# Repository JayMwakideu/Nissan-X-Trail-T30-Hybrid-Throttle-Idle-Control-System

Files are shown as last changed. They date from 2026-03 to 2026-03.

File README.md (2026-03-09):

# 🏎️ Nissan X-Trail T30 "Hybrid" Throttle & Idle Control System

### **Project Aim: Permanently Solving Electronic Throttle Body (ETB) Failure**

The Nissan X-Trail T30 (QR20DE/QR25DE) suffers from a notorious flaw: Electronic Throttle Body motor failure. This leads to erratic idling, Limp Mode, and expensive repairs.

This project bypasses the electronic failure points entirely by converting the system to a **Manual Cable-Driven Throttle**. An **Arduino-controlled Servo** is then used as a "helper" to manage critical idle air compensation (AC load, Power Steering load, and Cold Starts), creating a reliable, bulletproof solution.

---

## 🛠️ 1. Mechanical Modification: The "Hybrid" Body

To bypass the unreliable electronics, the throttle body must be physically modified to accept a manual accelerator cable and an idle-assist servo shaft.

### **Transformation Steps:**
1.  **Shaft Extension:** Weld a steel extension or a threaded bolt to the end of the main butterfly valve shaft.
2.  **The Pulley:** Attach a circular pulley to the new shaft extension for the manual accelerator cable.
3.  **The Helper Servo:** Mount a high-torque servo using a 3D-printed bracket. The servo arm "pushes" the throttle linkage to "crack" the butterfly open slightly (0–15%) to maintain idle.
4.  **Failsafe Return Spring:** **CRITICAL SAFETY STEP.** Install a heavy-duty external spring to ensure the throttle snaps shut if the cable or servo fails.

### **Modification Reference Photos**
*(Upload your photos to the repository to activate these links)*

| Modified Throttle Body | Engine Bay Installation | Gas Pedal Linkage |
| :---: | :---: | :---: |
| Throttle | Engine | Pedal |

---

## 🔌 2. Wiring & Electronics

The Arduino (Uno/Nano) acts as the new "Idle Control Unit," monitoring engine loads and adjusting the servo position in real-time.

### **Complete Wiring Table**

| Function | Pin | Component | Note |
| :--- | :--- | :--- | :--- |
| **RPM Input** | D2 | PC817 Optocoupler | Tapped from Ignition Coil (Must use Opto!) |
| **PSP Switch** | D3 | OEM Pressure Switch | Detects Power Steering load |
| **AC Signal** | D4 | AC Clutch Wire | Detects AC Compressor load |
| **Temp Sensor** | D6 | DS18B20 | Reads engine coolant temperature |
| **Servo Output** | D9 | MG996R / SG90 | Controls physical idle opening |
| **Display** | A4/A5 | SSD1306 OLED | I2C Data/Clock |
| **Buzzer** | D11 | Active 5V Buzzer | Stall Alarm (RPM < 550) |
| **Voltage** | A0 | Resistor Divider | Optional Battery Monitor (30k/7.5k) |

---

## 🖥️ 3. Software Logic & UI

The code uses a simplified PID loop to maintain target RPM based on input loads.

### **Dashboard Interface Gallery**
Here is a sequence showing the bootloader, main telemetry dash, and the EEPROM settings menu.

<table border="0">
  <tr>
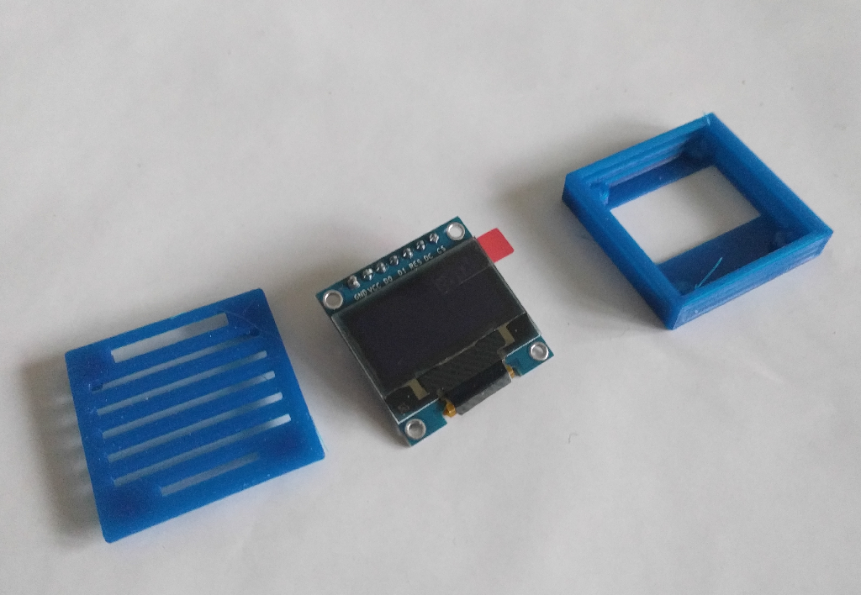
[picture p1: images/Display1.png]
    <td align="center"><br><em>Boot Logo</em></td>
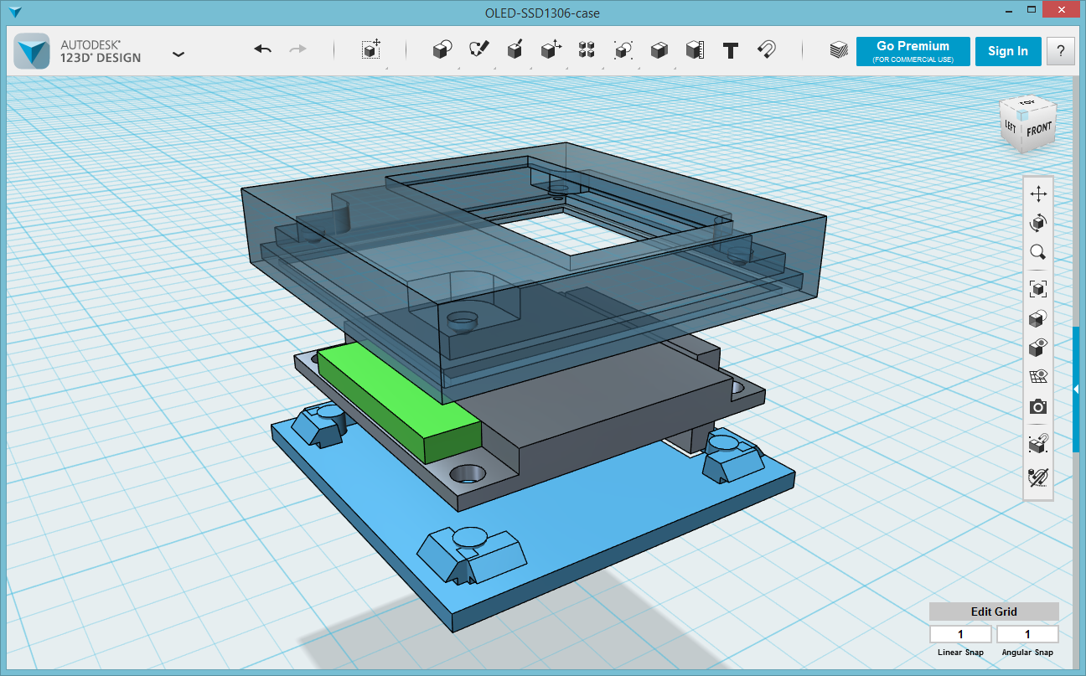
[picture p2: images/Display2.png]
    <td align="center"><br><em>Main Telemetry</em></td>
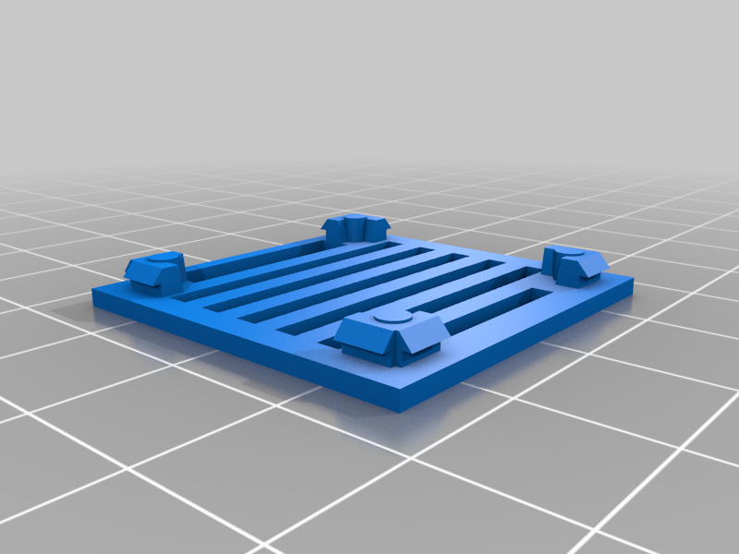
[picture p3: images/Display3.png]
    <td align="center"><br><em>Menu System</em></td>
  </tr>
  <tr>
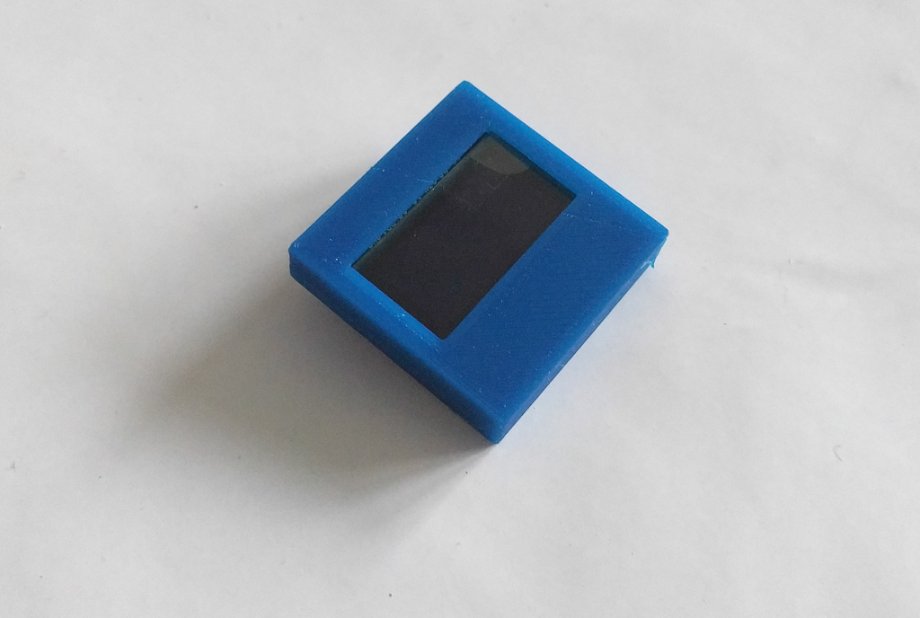
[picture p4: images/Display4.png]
    <td align="center"><br><em>Settings Adjust</em></td>
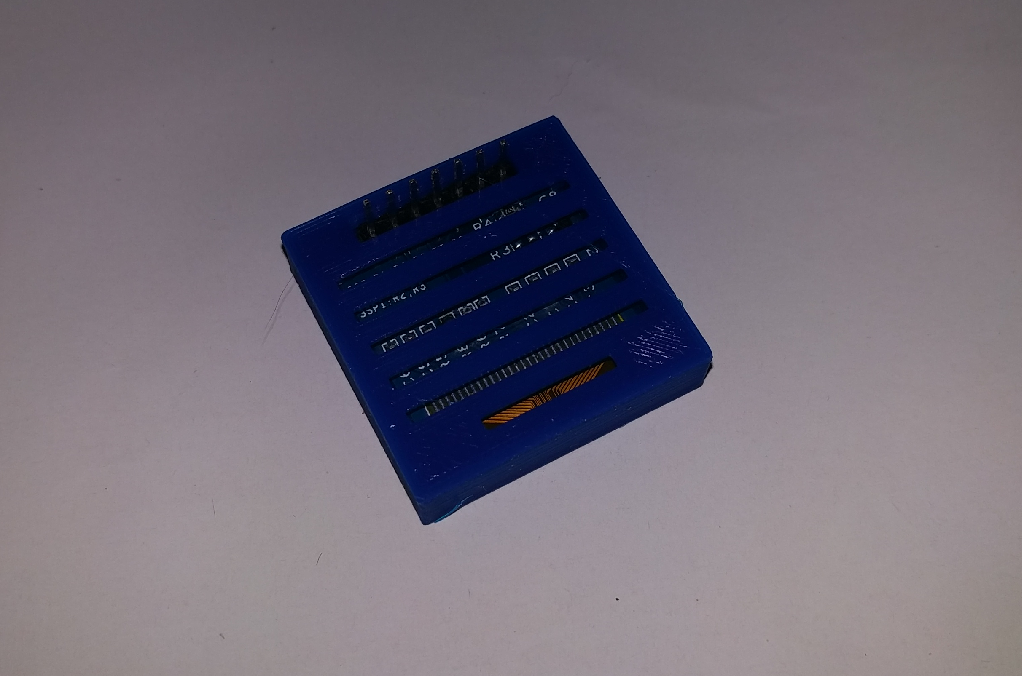
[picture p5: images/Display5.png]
    <td align="center"><br><em>Save Prompt</em></td>
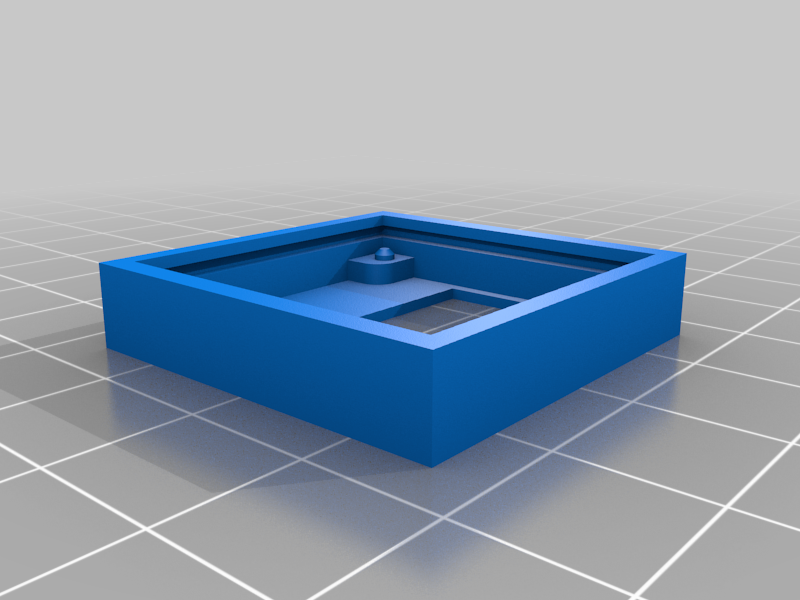
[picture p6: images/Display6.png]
    <td align="center"><br><em>Data Log View</em></td>
  </tr>
</table>

> **Note:** Long-press the **MENU** button to save your custom idle settings to EEPROM.

---

## 📐 4. 3D Printable Designs

The project relies on two distinct 3D printed assemblies.

### **A. Arduino Uno Control Casing**
This robust casing houses the main microcontroller, buttons, and the buzzer.

<table border="0">
  <tr>
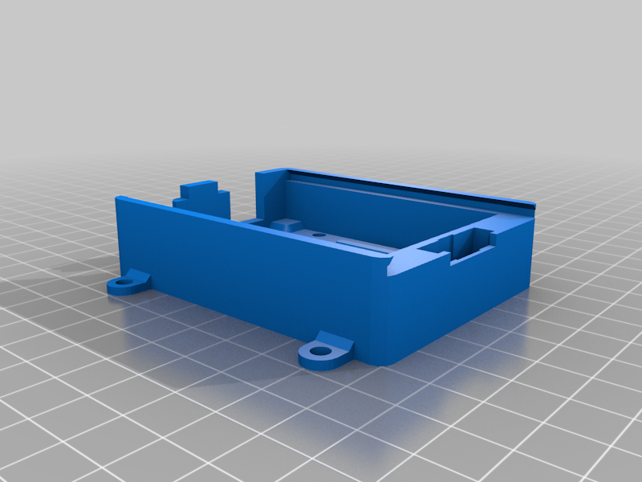
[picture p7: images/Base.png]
    <td align="center"><br><em>Main Base</em></td>
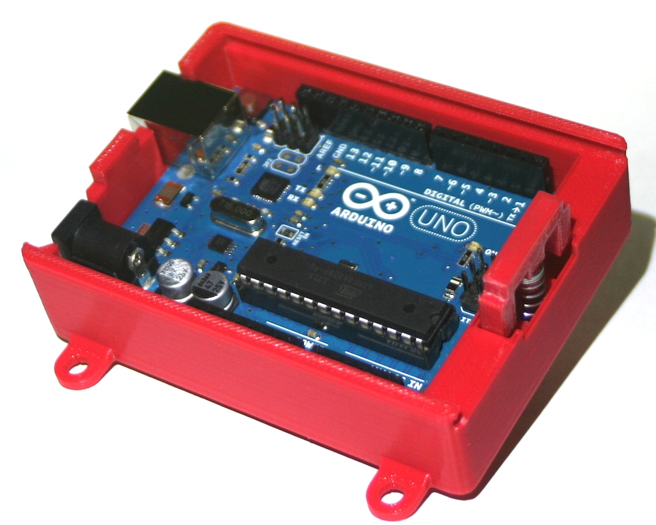
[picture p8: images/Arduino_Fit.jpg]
    <td align="center"><br><em>Uno Fitment</em></td>
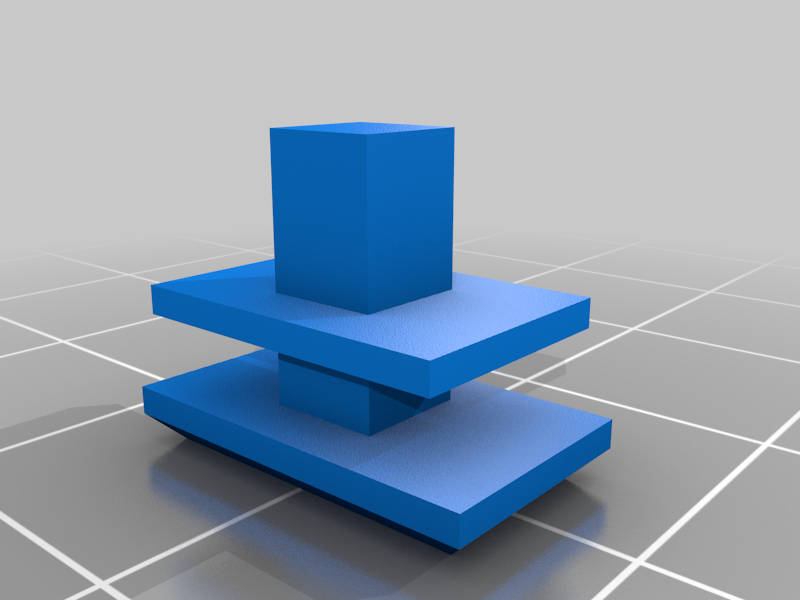
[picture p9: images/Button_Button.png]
    <td align="center"><br><em>Button Caps</em></td>
  </tr>
  <tr>
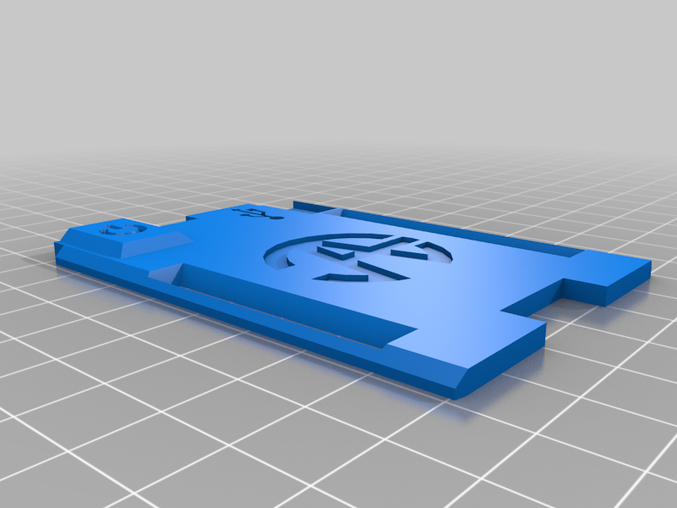
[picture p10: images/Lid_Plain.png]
    <td align="center"><br><em>Lid (Plain)</em></td>
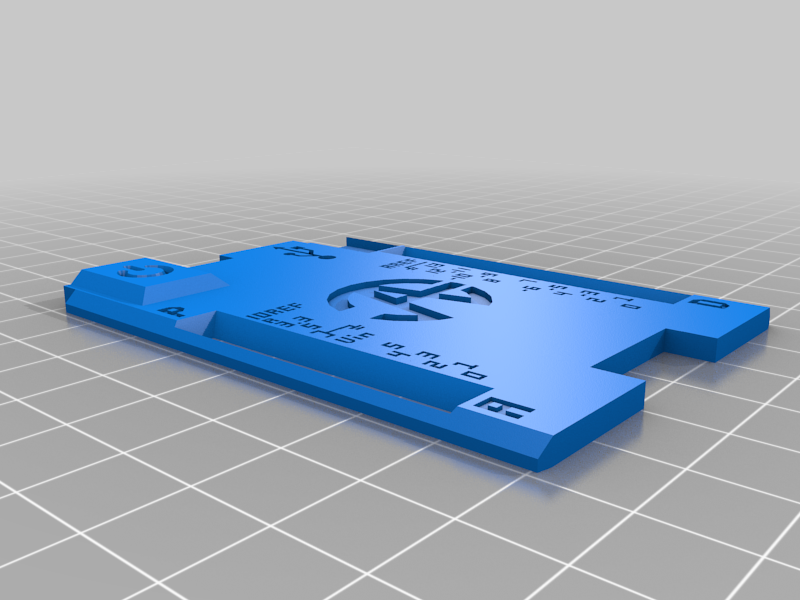
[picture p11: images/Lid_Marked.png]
    <td align="center"><br><em>Lid (Marked)</em></td>
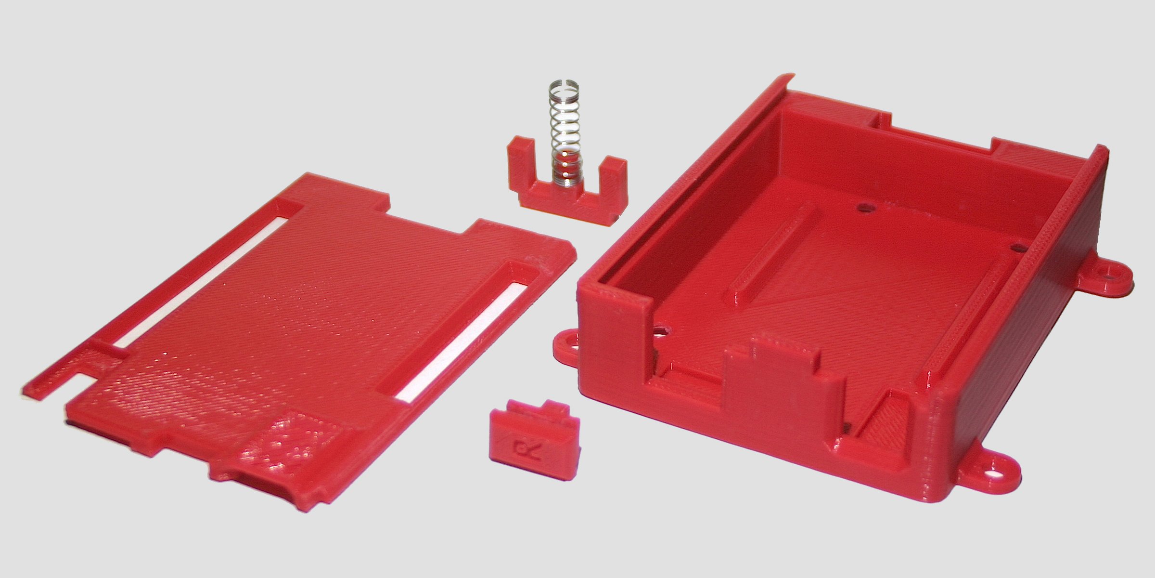
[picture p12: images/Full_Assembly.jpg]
    <td align="center"><br><em>Final Assembly</em></td>
  </tr>
</table>

#### **Download Uno Case STLs:**
* 📦 [Base.stl](/3D-files/Uno-case/Base.stl)
* 📦 [Lid_Plain.stl](/3D-files/Uno-case/Lid_Plain.stl)
* 📦 [Button_Button.stl](/3D-files/Uno-case/Button_Button.stl)
* 📦 [E-Lock.stl](/3D-files/Uno-case/E-Lock.stl)
* 📦 [Whole_Assembly.stl](/3D-files/Uno-case/Whole_Assembly.stl)

***

### **B. OLED Display & Dashboard Mount**
A dedicated enclosure for the 0.96" SSD1306 OLED, designed for easy dashboard integration.

<table border="0">
  <tr>
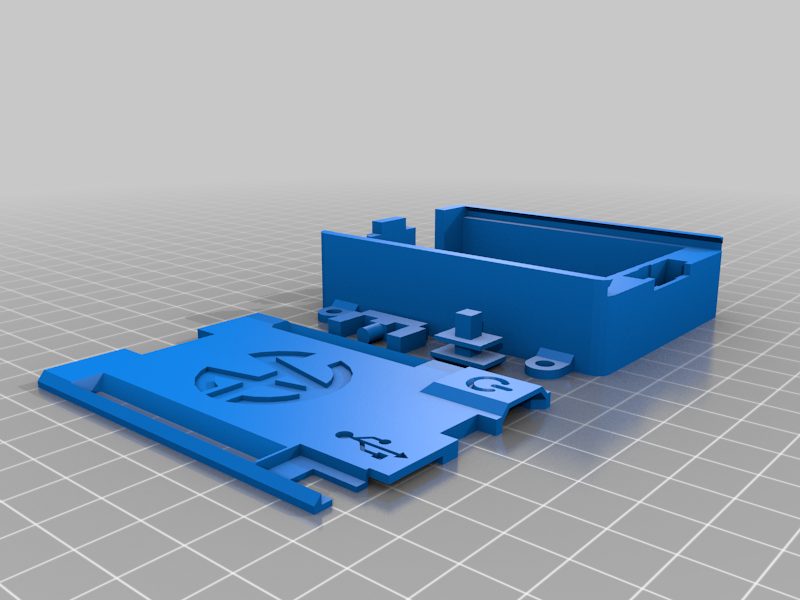
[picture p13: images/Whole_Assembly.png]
    <td align="center"><br><em>OLED Mount Concept</em></td>
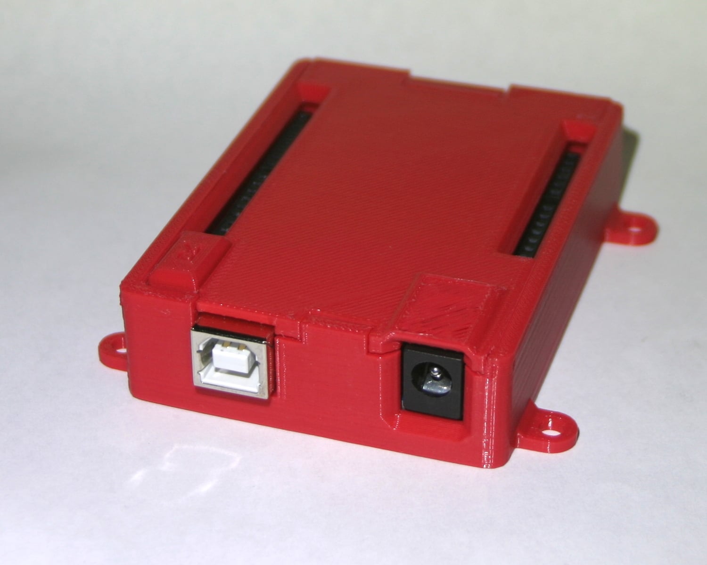
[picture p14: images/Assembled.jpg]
    <td align="center"><br><em>Physical Build</em></td>
  </tr>
</table>

#### **Download Display STLs:**
* 📦 [OLED_Case_Front.stl](/3D-files/Display/OLED-SSD1306-case-front.stl)
* 📦 [OLED_Case_Back.stl](/3D-files/Display/OLED-SSD1306-case-back.stl)
* 📂 [OLED_Case_Source.123dx](/3D-files/Display/OLED-SSD1306-case.123dx)

---

## 🚀 5. Installation & Operation Demos

### **Prototype Working Model (Table Test)**
Before installing on the vehicle, the system was validated on a bench setup.

Working Model

### **Operation Video**
*(Video link coming soon)*

<a href="https://www.youtube.com/watch?v=YOUR_VIDEO_ID_HERE" target="_blank">Watch the T30 Hybrid Throttle in Action</a>

---

## ⚠️ Safety Warning & Disclaimer

This is a custom mechanical modification to a critical vehicle system. **Use at your own risk.**

* **Failsafe:** Always ensure your **Mechanical Return Spring** is significantly stronger than the servo motor's output force. The spring must be able to snap the throttle closed even if the servo is active.
* **Fusing:** Use a **1A Fuse** on the 12V power supply to the Arduino.
* **Testing:** Perform your first engine start in Neutral with the handbrake firmly engaged.

---

## 🤝 Contributing

Built by **Jay Overlander**. If you have improved the PID tuning values for the QR20DE engine or designed a better bracket, feel free to submit a Pull Request!

For support or questions, email me at: **jmwakideu@jaylansolutions.co.ke**

---

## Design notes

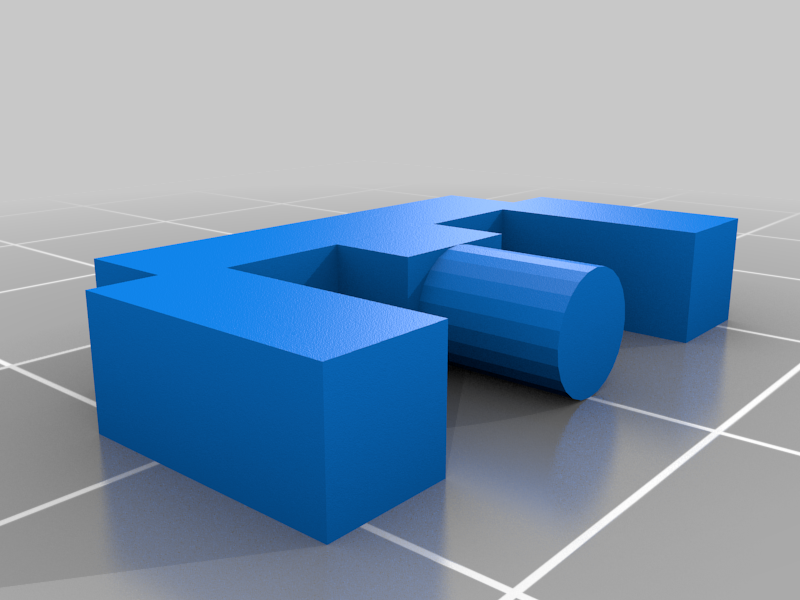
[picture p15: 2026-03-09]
images/E-Lock.png

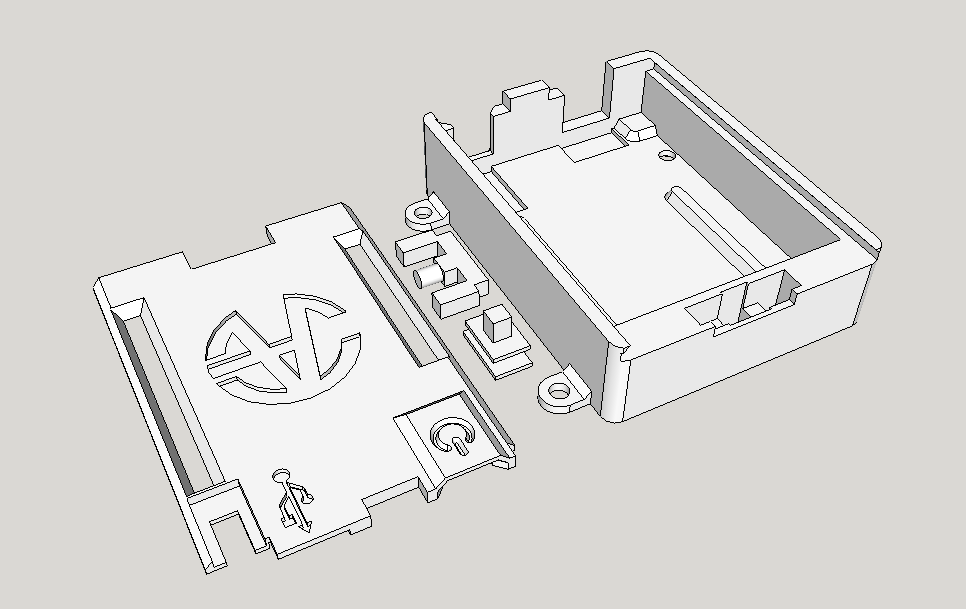
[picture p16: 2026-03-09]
images/Screen_Shot_2015-04-07_at_5.00.05_PM.png

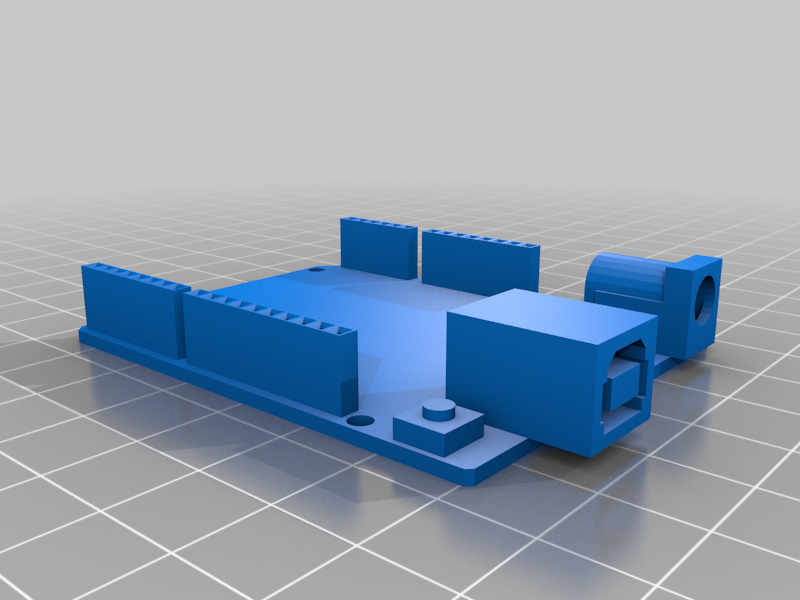
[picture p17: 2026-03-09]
images/Arduino_Reference_Model.png

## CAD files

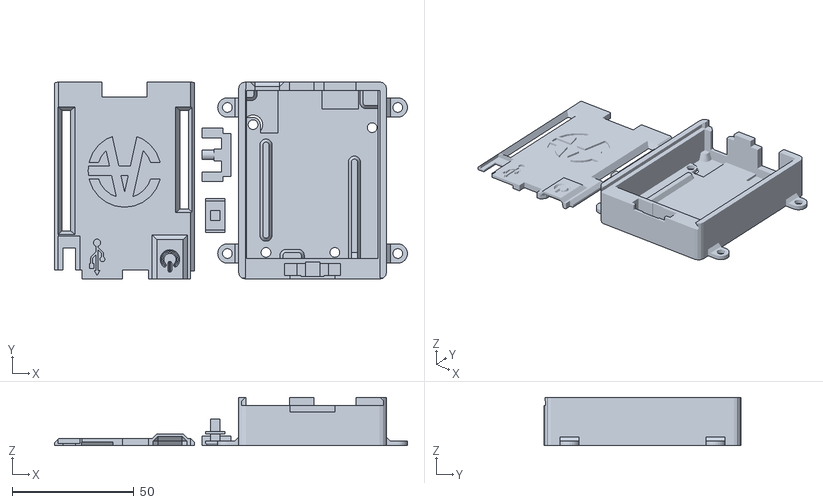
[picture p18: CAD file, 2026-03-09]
3D-files/Uno-case/Whole_Assembly.stl
145.0 x 81.1 x 19.9

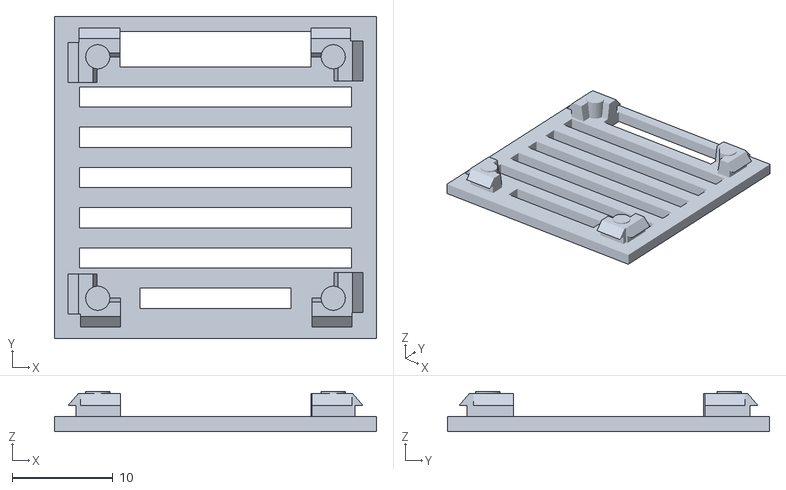
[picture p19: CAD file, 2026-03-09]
3D-files/Display/OLED-SSD1306-case-back.stl
32.0 x 32.0 x 4.00

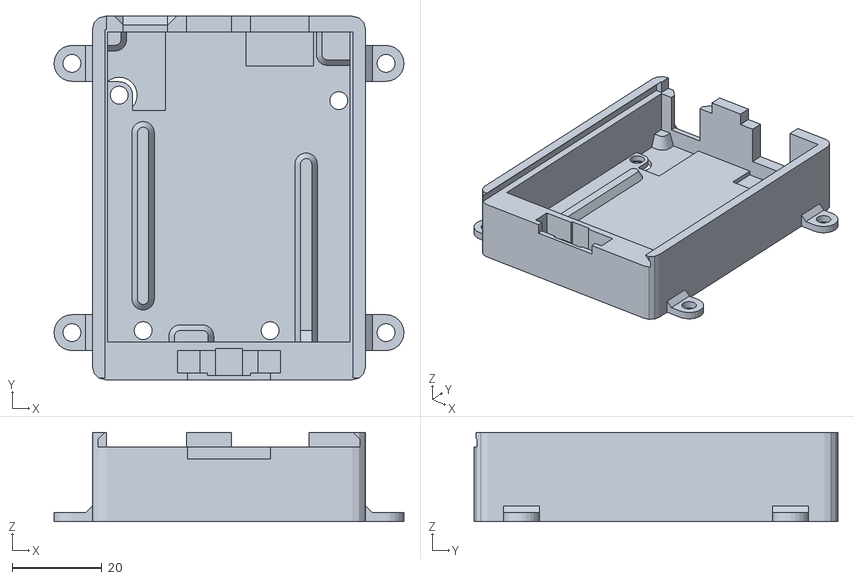
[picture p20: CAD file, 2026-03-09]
3D-files/Uno-case/Base.stl
78.0 x 81.1 x 19.9

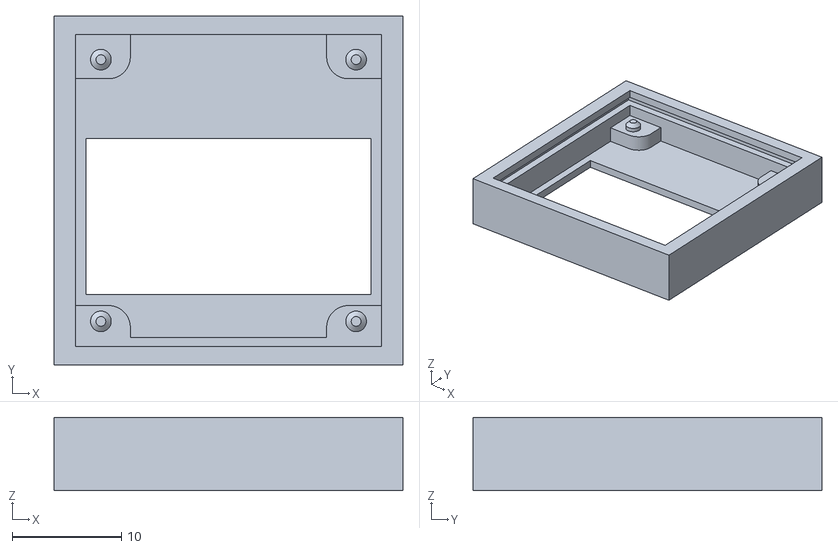
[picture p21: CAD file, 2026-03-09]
3D-files/Display/OLED-SSD1306-case-front.stl
32.0 x 32.0 x 6.70

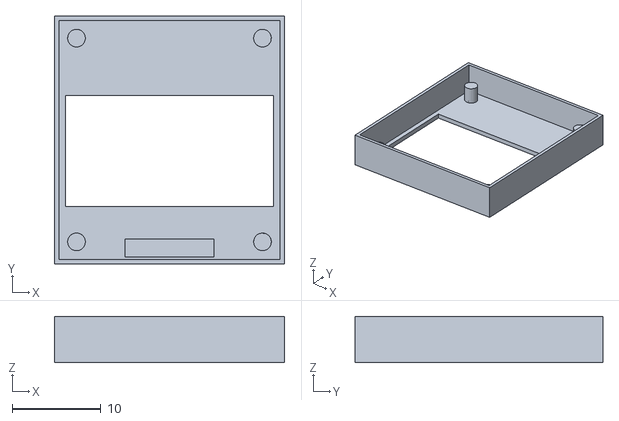
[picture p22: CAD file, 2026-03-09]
3D-files/Uno-case/096_inch_OLED_case.stl
26.0 x 28.0 x 5.20

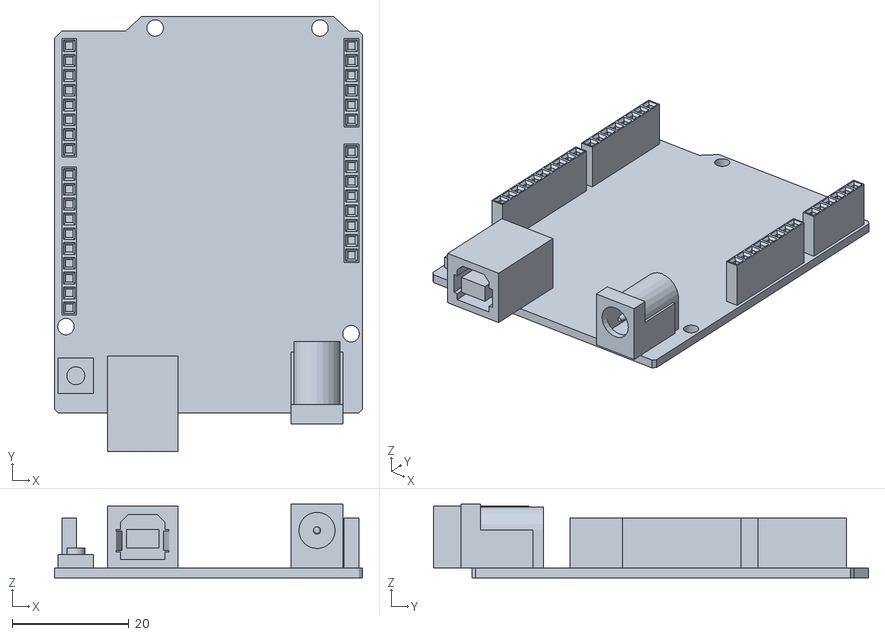
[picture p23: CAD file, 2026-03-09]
3D-files/Uno-case/Arduino_Reference_Model.stl
52.9 x 74.7 x 12.6

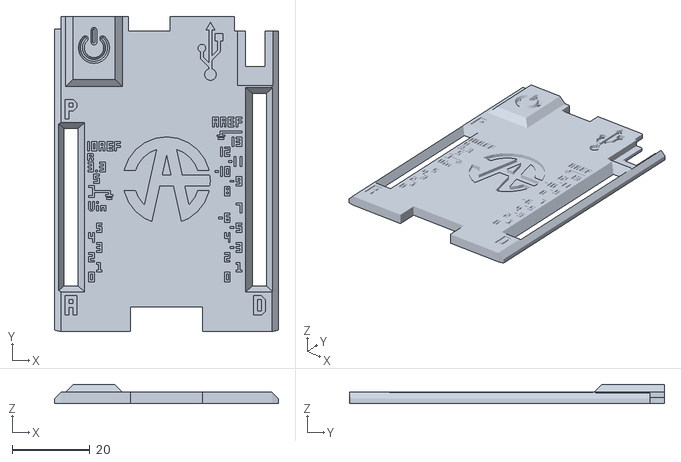
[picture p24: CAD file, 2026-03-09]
3D-files/Uno-case/Lid_Marked.stl
57.6 x 81.1 x 4.89

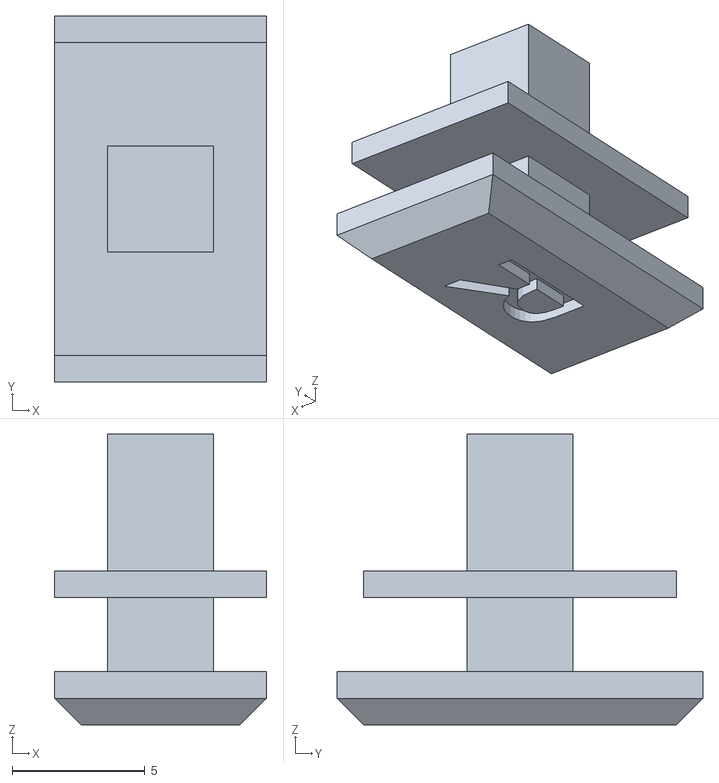
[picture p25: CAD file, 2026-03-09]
3D-files/Uno-case/Button_Button.stl
8.00 x 13.8 x 11.0

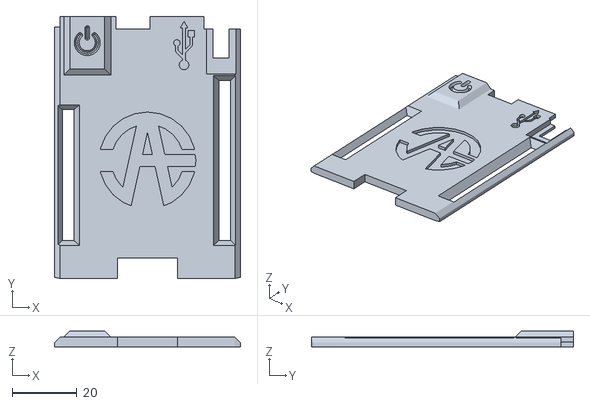
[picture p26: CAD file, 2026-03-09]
3D-files/Uno-case/Lid_Plain.stl
57.6 x 81.1 x 4.89

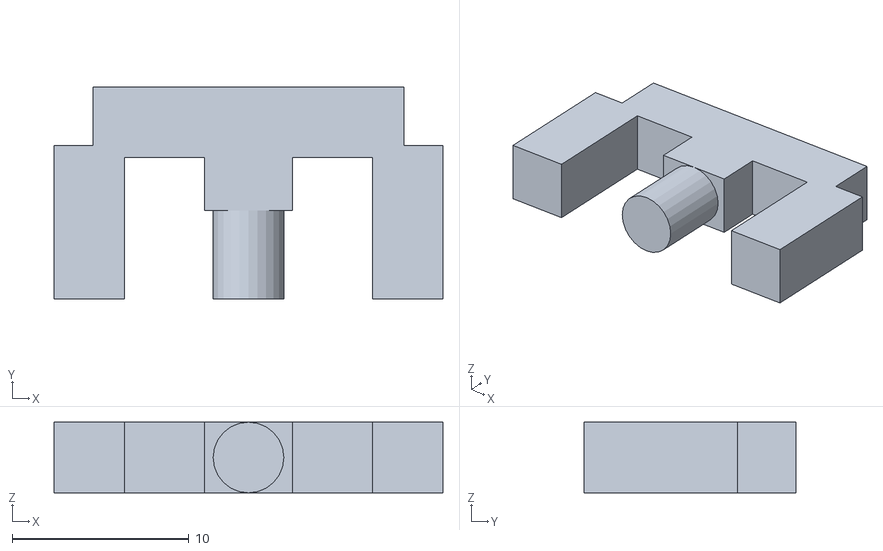
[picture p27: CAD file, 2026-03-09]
3D-files/Uno-case/E-Lock.stl
22.0 x 12.0 x 4.00

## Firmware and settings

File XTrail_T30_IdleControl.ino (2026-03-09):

#include <Servo.h>
#include <Wire.h>
#include <Adafruit_GFX.h>
#include <Adafruit_SSD1306.h>
#include <OneWire.h>
#include <DallasTemperature.h>
#include <EEPROM.h>

// OLED setup
#define SCREEN_WIDTH 128
#define SCREEN_HEIGHT 64
Adafruit_SSD1306 display(SCREEN_WIDTH, SCREEN_HEIGHT, &Wire, -1);

// Pins
#define RPM_PIN 2
#define PSP_PIN 3
#define AC_PIN 4
#define TEMP_PIN 6
#define BTN_MENU 7
#define BTN_UP 8
#define SERVO_PIN 9
#define BTN_DOWN 10
#define BUZZER_PIN 11
#define VOLT_PIN A0

// EEPROM addresses
#define EEPROM_BASE 0
#define EEPROM_COLD 2
#define EEPROM_AC   4

// Variables
volatile int pulseCount = 0;
OneWire oneWire(TEMP_PIN);
DallasTemperature sensors(&oneWire);

float rpm = 0;
float temp = 0;
float voltage = 0;
int servoPos = 0;

// PID variables
float Kp = 0.35;
float Ki = 0.02;
float Kd = 0.08;
float error = 0;
float lastError = 0;
float integral = 0;

// Tuning parameters
int baseIdle = 750;
int coldIdle = 1000;
int acAdd = 100;

// Menu
int menuState = 0;

// Stall warning
int stallThreshold = 500;

// Servo
Servo throttle;

// Pulse counting
void countPulse() { pulseCount++; }

// EEPROM functions
void saveSettings() {
  EEPROM.put(EEPROM_BASE, baseIdle);
  EEPROM.put(EEPROM_COLD, coldIdle);
  EEPROM.put(EEPROM_AC, acAdd);
}

void loadSettings() {
  EEPROM.get(EEPROM_BASE, baseIdle);
  EEPROM.get(EEPROM_COLD, coldIdle);
  EEPROM.get(EEPROM_AC, acAdd);
}

// Boot animation
void bootScreen() {
  display.clearDisplay();
  display.setTextSize(2);
  display.setCursor(10,5);
  display.println("X-Trail T30");
  display.setTextSize(1);
  display.setCursor(30,30);
  display.println("Jay Overlander");

  // Loading bar
  display.drawRect(10,50,108,8,WHITE);
  for(int i=0;i<=108;i+=4){
    display.fillRect(10,50,i,8,WHITE);
    display.display();
    delay(50);
  }
}

// Startup diagnostics
void startupDiagnostics() {
  display.clearDisplay();
  display.setTextSize(1);
  display.setCursor(0,0);
  display.println("STARTUP CHECK");

  display.println(rpm>0?"RPM OK":"RPM FAIL");
  display.println(temp>0?"TEMP OK":"TEMP FAIL");
  display.println(voltage>0?"VOLT OK":"VOLT FAIL");

  throttle.write(5); // Servo test
  delay(500);
  throttle.write(0);

  display.display();
  delay(2000);
}

// Menu handler
void handleMenu() {
  static unsigned long lastPress = 0;
  unsigned long now = millis();
  
  if(!digitalRead(BTN_MENU) && now - lastPress > 300){
    menuState++;
    if(menuState>3) menuState=0;
    lastPress = now;
  }

  if(menuState==1){
    if(!digitalRead(BTN_UP)) { baseIdle+=10; delay(100); }
    if(!digitalRead(BTN_DOWN)) { baseIdle-=10; delay(100); }
  } else if(menuState==2){
    if(!digitalRead(BTN_UP)) { coldIdle+=10; delay(100); }
    if(!digitalRead(BTN_DOWN)) { coldIdle-=10; delay(100); }
  } else if(menuState==3){
    if(!digitalRead(BTN_UP)) { acAdd+=10; delay(100); }
    if(!digitalRead(BTN_DOWN)) { acAdd-=10; delay(100); }
  }

  // Long press MENU to save
  if(!digitalRead(BTN_MENU) && now - lastPress > 1000){
    saveSettings();
    lastPress = now;
  }
}

// Draw dashboard
void drawDashboard(int targetRPM, bool ac, bool steer){
  display.clearDisplay();
  display.setTextSize(1);

  // Text info
  display.setCursor(0,0);
  display.print("RPM:");
  display.print(rpm);
  display.print(" T:");
  display.print(targetRPM);

  display.setCursor(0,10);
  display.print("TMP:");
  display.print(temp);

  display.setCursor(64,10);
  if(voltage>0.1) display.print("V:"); else display.print("V:---");
  if(voltage>0.1) display.print(voltage);

  display.setCursor(0,20);
  display.print("AC:");
  display.print(ac?"ON":"OFF");

  display.setCursor(64,20);
  display.print("STR:");
  display.print(steer?"ON":"OFF");

  // Servo bar
  display.setCursor(0,32);
  display.print("SERVO");
  int servoBar = map(servoPos,0,30,0,108);
  display.drawRect(10,42,108,8,WHITE);
  display.fillRect(10,42,servoBar,8,WHITE);

  // Graphical RPM dial
  int centerX=100, centerY=54, radius=10;
  display.drawCircle(centerX, centerY, radius, WHITE);
  float angle = map(rpm,0,2000,135,45);
  float rad = angle * 3.1416 / 180.0;
  int x = centerX + radius * cos(rad);
  int y = centerY - radius * sin(rad);
  display.drawLine(centerX, centerY, x, y, WHITE);

  // Stall warning
  if(rpm<stallThreshold){
    display.setCursor(0,56);
    display.print("!!LOW RPM!!");
    digitalWrite(BUZZER_PIN,HIGH);
  } else digitalWrite(BUZZER_PIN,LOW);

  display.display();
}

void setup(){
  throttle.attach(SERVO_PIN);

  pinMode(RPM_PIN,INPUT);
  pinMode(PSP_PIN,INPUT_PULLUP);
  pinMode(AC_PIN,INPUT);
  pinMode(BTN_MENU,INPUT_PULLUP);
  pinMode(BTN_UP,INPUT_PULLUP);
  pinMode(BTN_DOWN,INPUT_PULLUP);
  pinMode(BUZZER_PIN,OUTPUT);

  attachInterrupt(digitalPinToInterrupt(RPM_PIN),countPulse,FALLING);

  sensors.begin();
  loadSettings();
  display.begin(SSD1306_SWITCHCAPVCC,0x3C);
  bootScreen();
  startupDiagnostics();
}

void loop(){
  delay(500);

  rpm = pulseCount*30;   // Calculate RPM from coil signal
  pulseCount = 0;

  sensors.requestTemperatures();  
  temp = sensors.getTempCByIndex(0); // Temperature from DS18B20

  voltage = analogRead(VOLT_PIN)*(15.0/1023.0); // Optional Battery Voltage input

  bool ac = digitalRead(AC_PIN); // Read AC signal
  bool steer = !digitalRead(PSP_PIN); // Read Power Steering Pressure Switch

  int targetRPM = baseIdle;
  if(temp<40) targetRPM = coldIdle;
  if(ac) targetRPM += acAdd;
  if(steer) targetRPM += 150;

  // PID control
  error = targetRPM - rpm;
  integral += error;
  float derivative = error - lastError;
  float output = Kp*error + Ki*integral + Kd*derivative;
  servoPos += output;
  servoPos = constrain(servoPos,0,30);
  throttle.write(servoPos
